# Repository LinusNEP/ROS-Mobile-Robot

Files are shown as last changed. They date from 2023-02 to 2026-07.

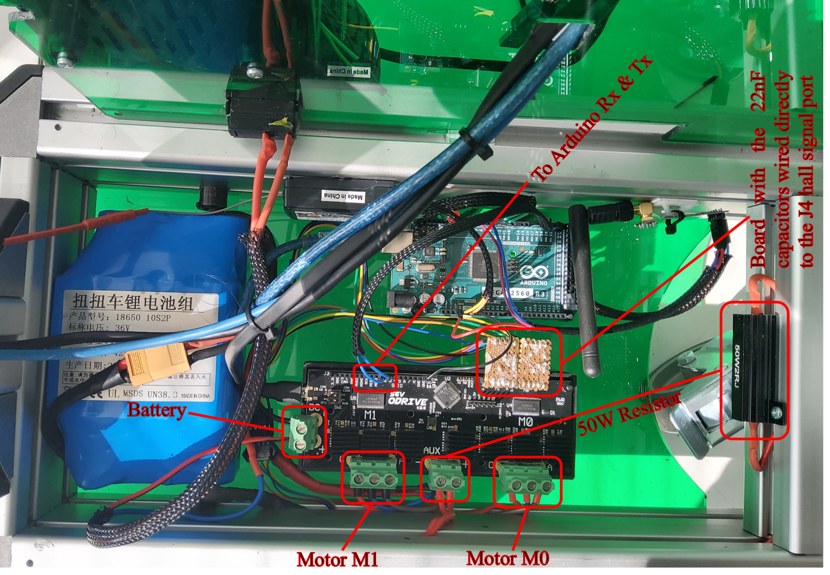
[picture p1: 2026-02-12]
docs/gallery-4.png

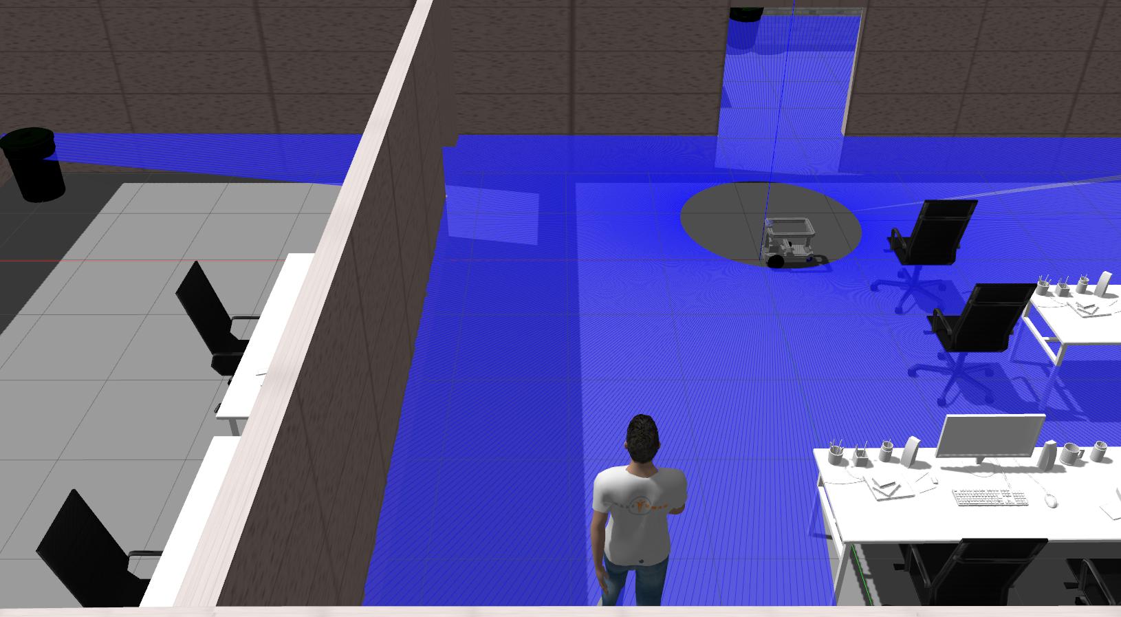
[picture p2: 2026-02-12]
docs/gallery-2.jpg

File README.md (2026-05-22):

## ROMR: A ROS-Based Open-Source Mobile Robot






ROMR is an open-source, low-cost, high-payload autonomous platform designed for research, logistics, and education. This repository contains the necessary files for its  design and development. ROMR utilises off-the-shelf (OTS) components, additive-manufactured parts, aluminium profiles, and a consumer hoverboard with high-torque brushless direct current (BLDC) motors. It is fully compatible with the robot operating system (ROS), has a maximum payload of 90kg, and costs less than $1500. Furthermore, ROMR offers a simple yet robust framework for contextualising simultaneous localisation and mapping (SLAM) algorithms, an essential prerequisite for autonomous robot navigation.

All the design, construction and software files are publicly available under the GNU GPL v3 license. A descriptive video of ROMR can be found at https://osf.io/ku8ag.

More information can be found on the [Project Website](https://linusnep.github.io/ROS-Mobile-Robot/).

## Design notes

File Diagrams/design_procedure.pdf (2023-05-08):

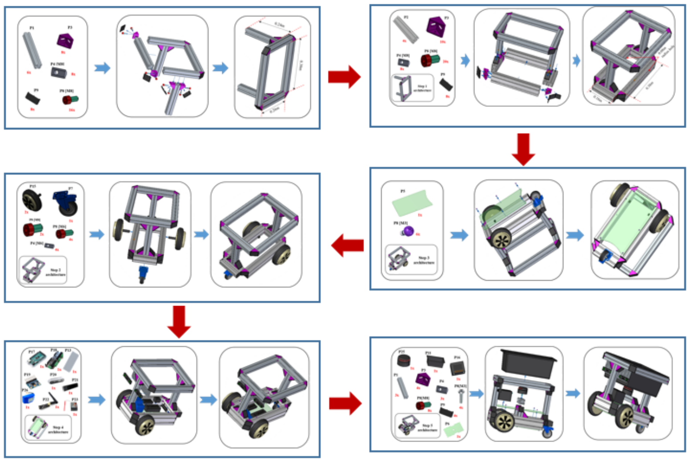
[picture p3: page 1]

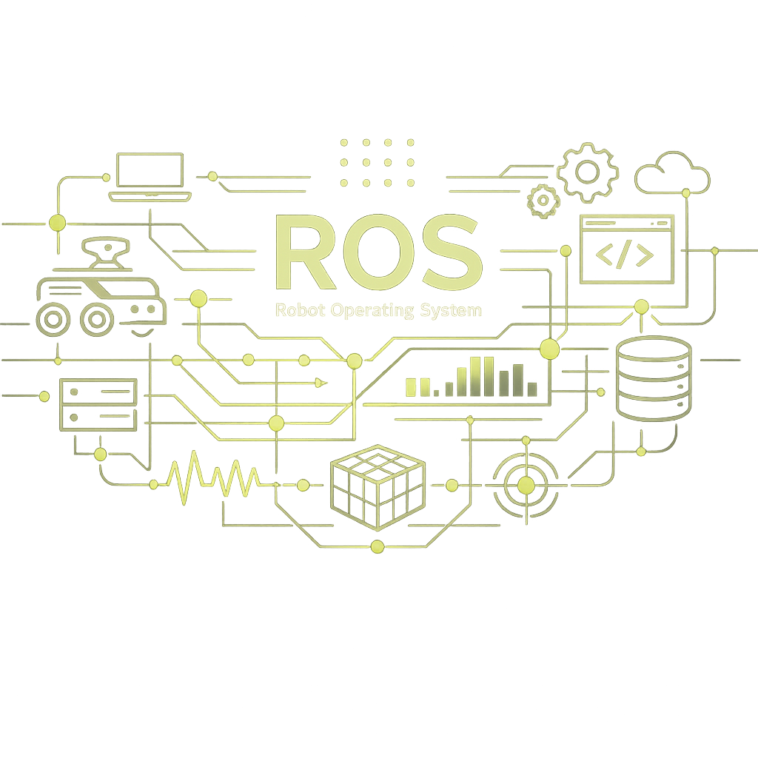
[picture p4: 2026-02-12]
docs/feature-ros.png

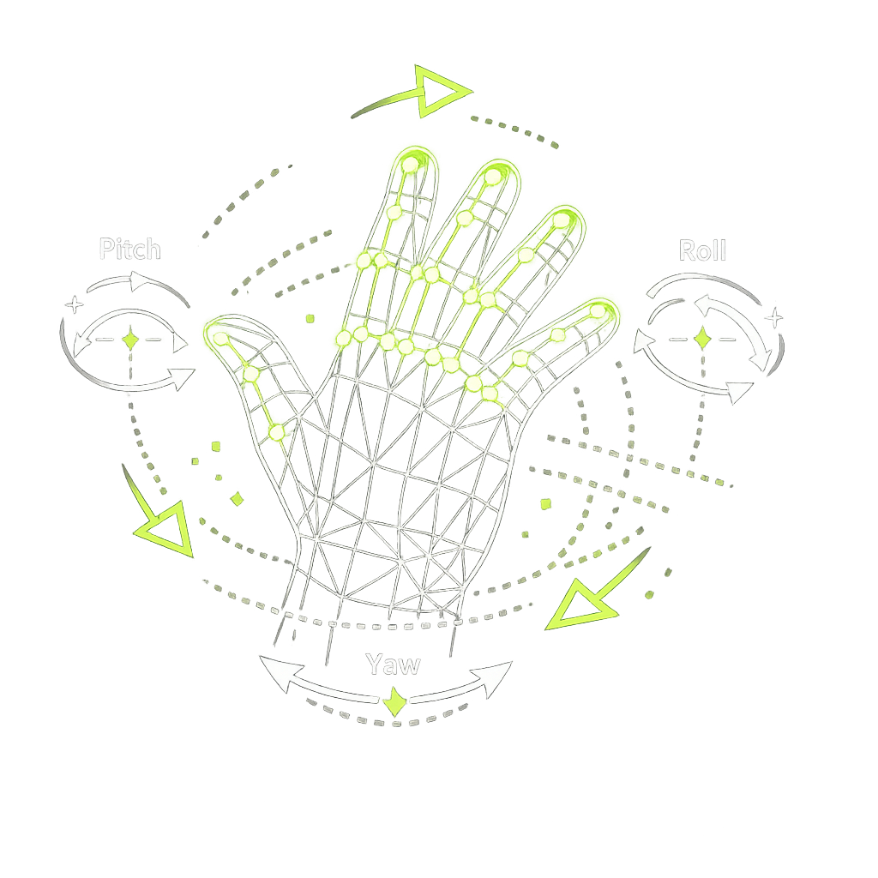
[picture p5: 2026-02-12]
docs/feature-gesture.png

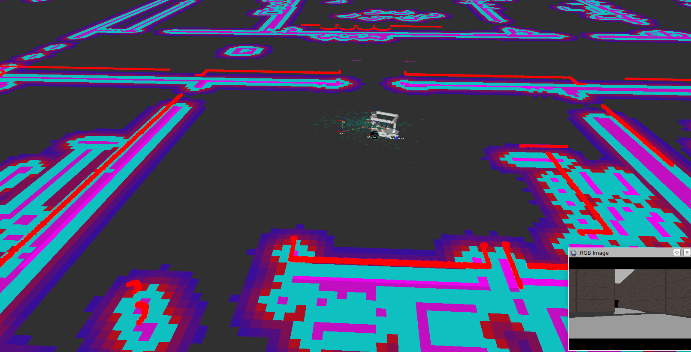
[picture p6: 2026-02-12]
docs/gallery-3.png

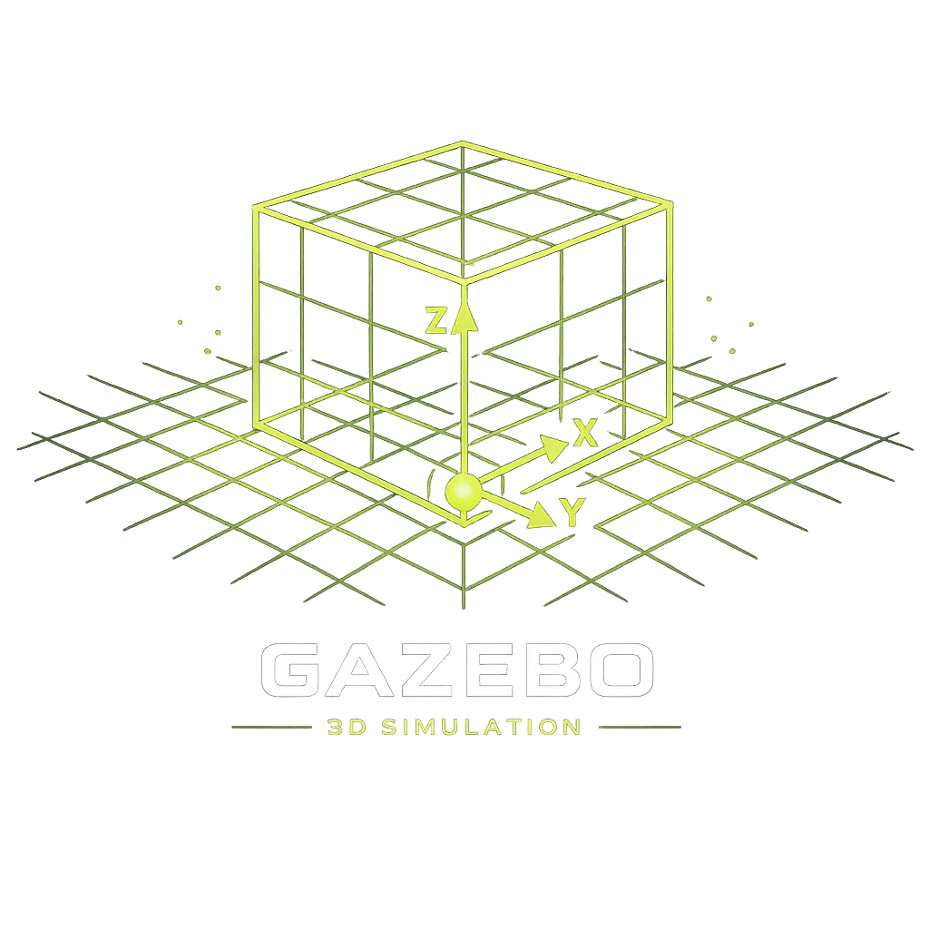
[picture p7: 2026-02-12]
docs/feature-simulation.png

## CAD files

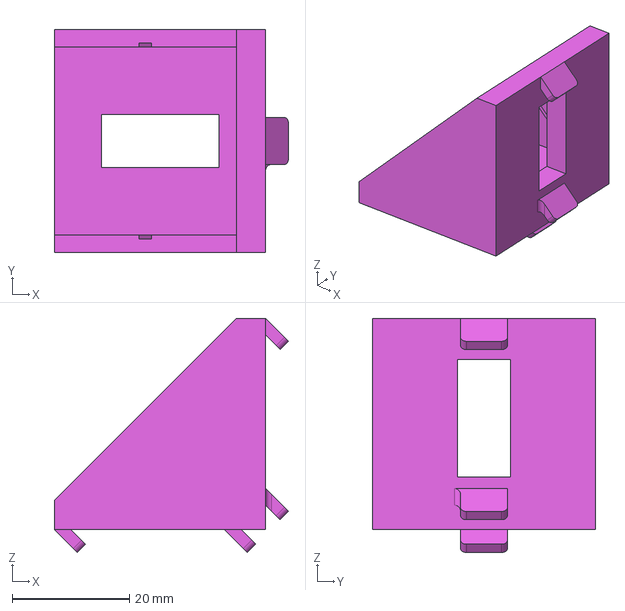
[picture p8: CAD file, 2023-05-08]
CAD & PNG Files/Corner_bracket_I_type.stp
39.9 x 38.0 x 39.9 mm

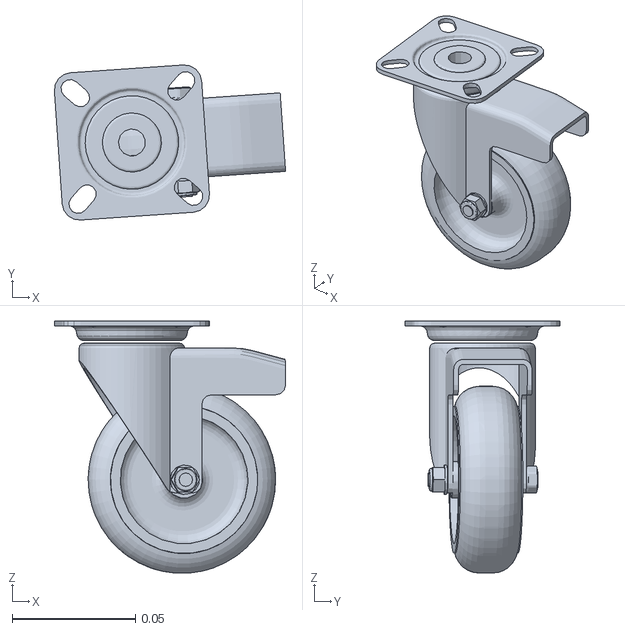
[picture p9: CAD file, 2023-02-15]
romr_ros/src/meshes/casterwheel.STL
0.094 x 0.063 x 0.102

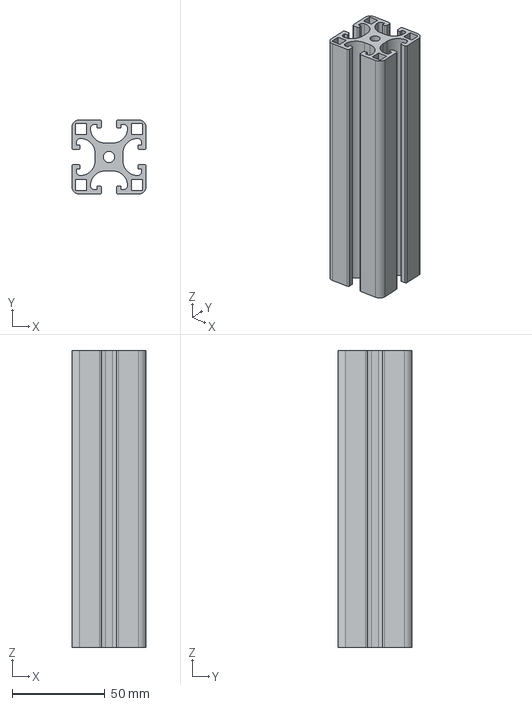
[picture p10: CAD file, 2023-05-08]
CAD & PNG Files/Alu_profil_40x40x165.stp
40.0 x 40.0 x 160.0 mm

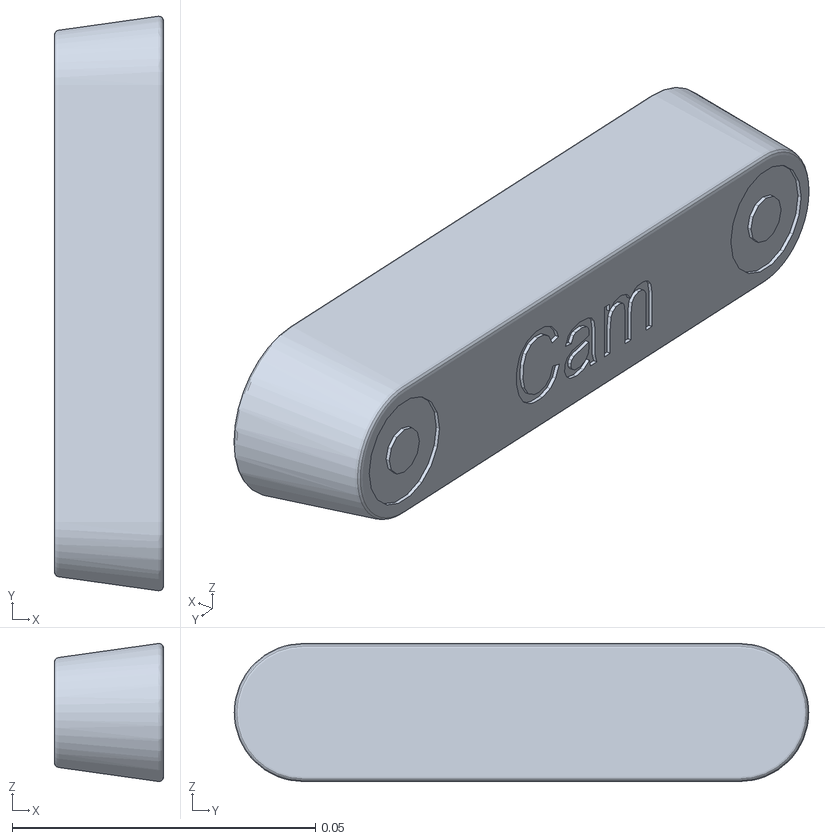
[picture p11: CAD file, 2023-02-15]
romr_ros/src/meshes/camerad435i.STL
0.018 x 0.0948 x 0.0228

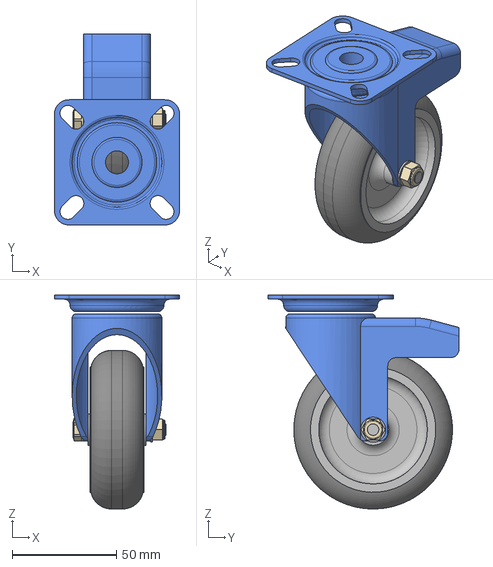
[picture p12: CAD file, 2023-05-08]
CAD & PNG Files/Swivel caster.stp
60.0 x 91.5 x 102.5 mm

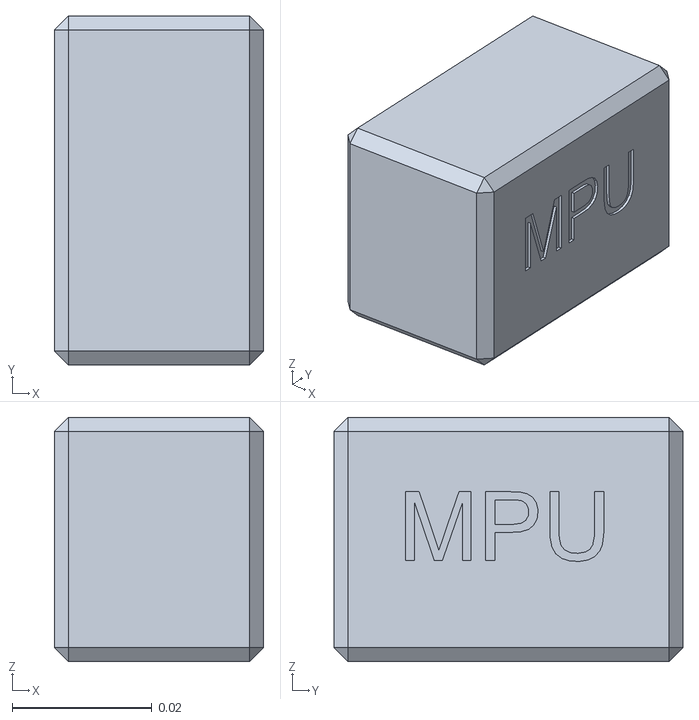
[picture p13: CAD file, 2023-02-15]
romr_ros/src/meshes/imu.STL
0.03 x 0.05 x 0.035

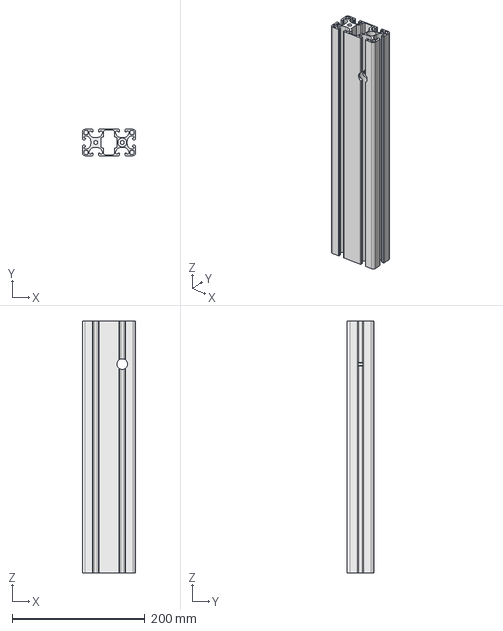
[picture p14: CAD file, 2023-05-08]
CAD & PNG Files/Alu_profil_80x40.stp
80.0 x 40.0 x 380.0 mm

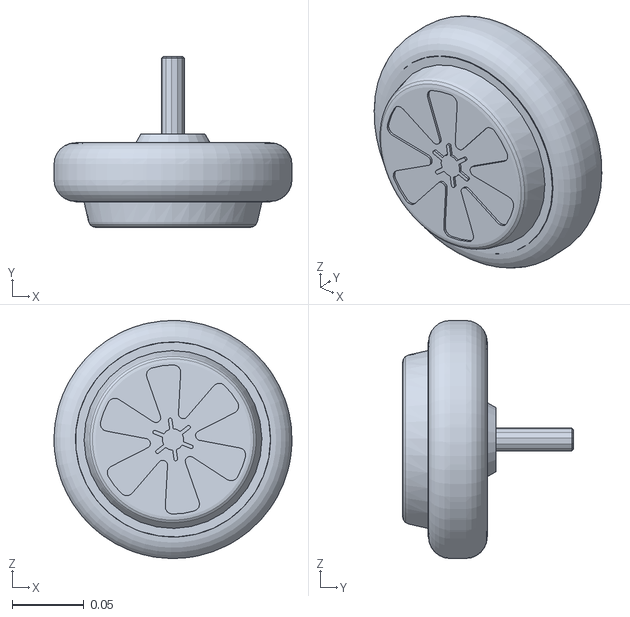
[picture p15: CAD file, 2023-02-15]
romr_ros/src/meshes/rightwheel.STL
0.166 x 0.119 x 0.166

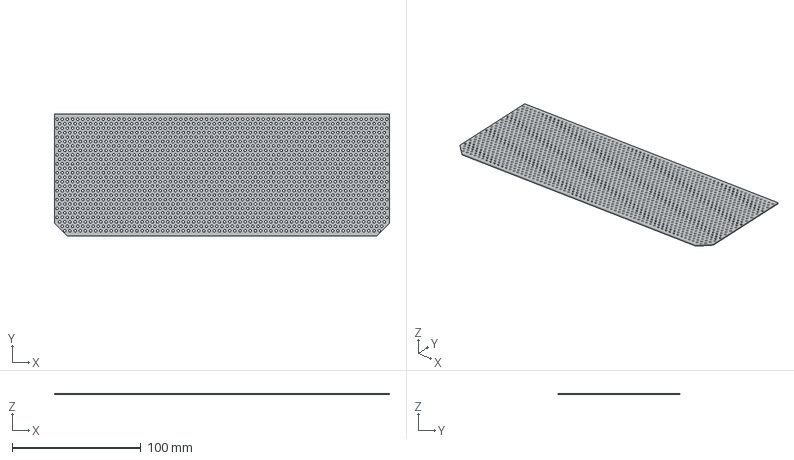
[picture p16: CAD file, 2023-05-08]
CAD & PNG Files/Holeplate_front.stp
260.0 x 95.0 x 1.00 mm

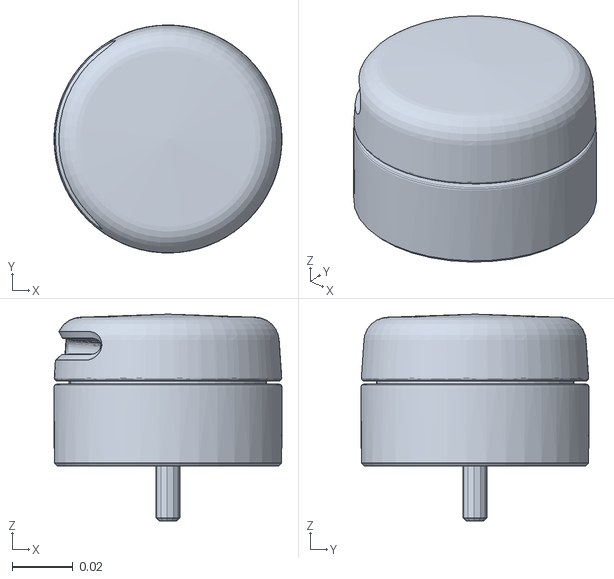
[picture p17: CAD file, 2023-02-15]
romr_ros/src/meshes/lidar.STL
0.075 x 0.075 x 0.068

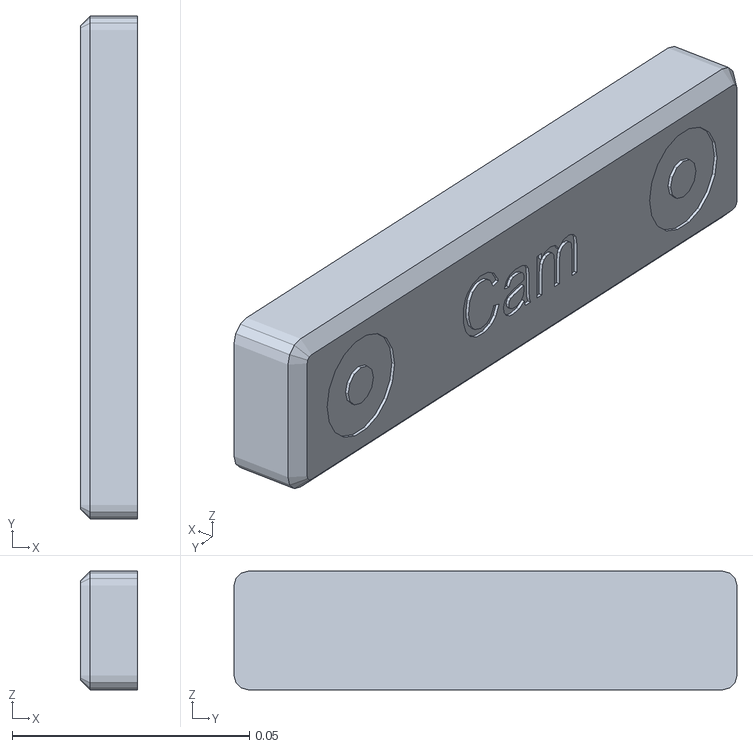
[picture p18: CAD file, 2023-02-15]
romr_ros/src/meshes/camerat265.STL
0.012 x 0.106 x 0.025

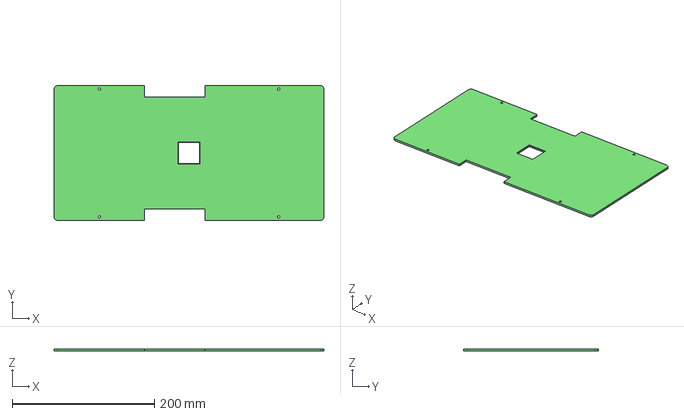
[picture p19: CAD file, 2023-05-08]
CAD & PNG Files/Top_Cover.stp
380.0 x 190.0 x 3.00 mm

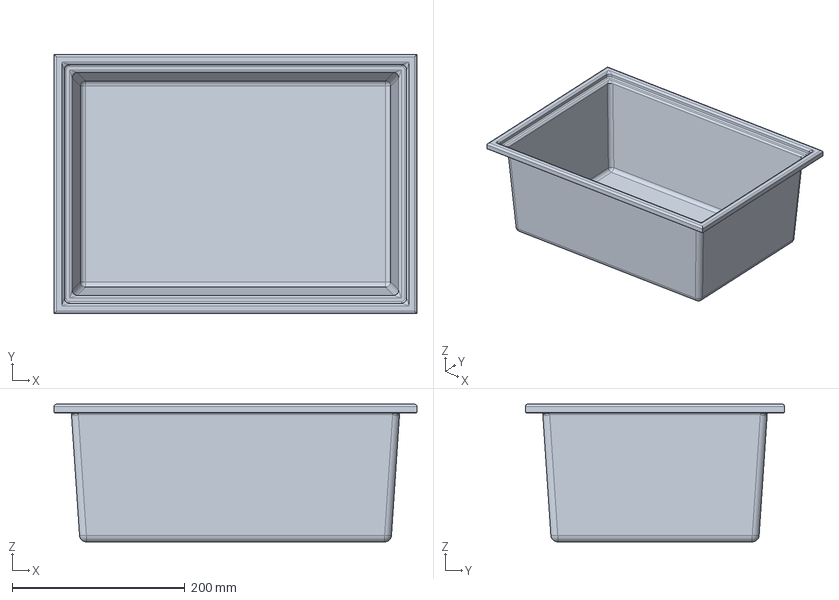
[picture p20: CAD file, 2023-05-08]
CAD & PNG Files/0.42x0.32x0.15m box.stp
420.0 x 300.0 x 159.4 mm

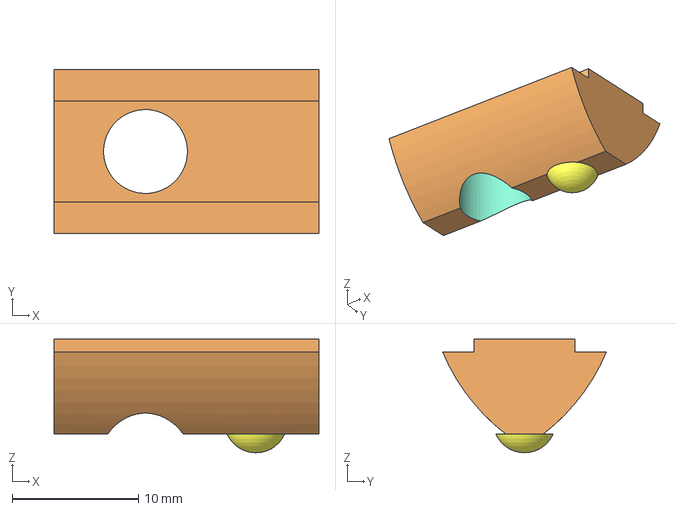
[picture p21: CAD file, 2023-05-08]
CAD & PNG Files/Mountig_Bracket_M8.stp
21.0 x 13.0 x 9.00 mm

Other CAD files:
romr_ros/src/meshes/leftwheel.STL
CAD & PNG Files/Corner_bracket_cover_cap.stp
CAD & PNG Files/Drive_Wheel.stp
CAD & PNG Files/Bottom_Cover.stp
CAD & PNG Files/Assembly_Robot.x_t
CAD & PNG Files/Bolt_M8x16.stp
CAD & PNG Files/lock_nut.stp
CAD & PNG Files/rplidar_base_holder.STL

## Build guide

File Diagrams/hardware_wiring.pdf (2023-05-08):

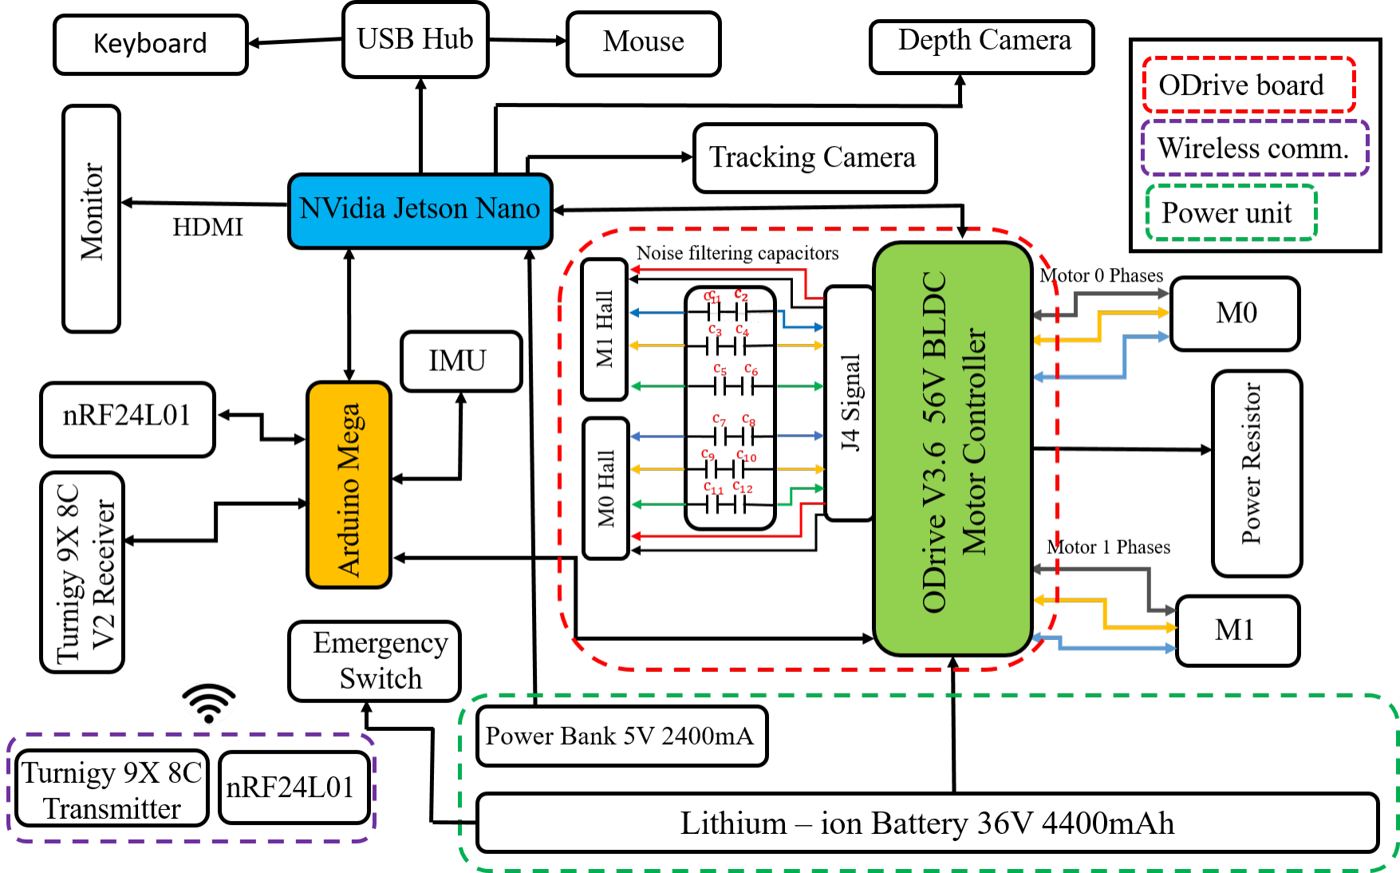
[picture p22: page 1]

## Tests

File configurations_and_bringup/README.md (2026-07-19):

# ROMR ODrive Calibration & Bringup

This directory provides everything needed to get started with ROMR setup and calibration. The structure is as follows: configure parameters, calibrate motors and halls, verify operation over USB, wire up the Arduino, then stack ROS on top. Each step is independent and builds on the last.

---

## Hardware

- **ODrive 3.6** (24 V or 56 V variant) with firmware 0.5.4
- **Two hoverboard hub motors** with 15 pole pairs and 3 hall sensors each
- **Arduino Mega 2560**
- **Jetson Nano** running Ubuntu 18.04 + ROS 1 Melodic (or compatible, e.g., Laptop or Mini-PCs: ROS Noetic and ROS 2)
- **36 V Li-ion battery pack** (10S), optionally with brake resistor
- **RC transmitter/receiver** with at least 3 channels (for RC control)
- **Android device** with the ROS-Mobile app (for WiFi teleop)

If your setup differs, e.g., different ODrive board, different motors, different battery, then the constants at the top of `odrive_parameter_configuration.py` **must be reviewed** before running. Voltage trip levels in particular are safety-critical: wrong values either prevent motor start or cause a fault on the first hard brake.

---

## File overview

### Python - ODrive host scripts

| File | Purpose |
|---|---|
| `odrive_parameter_configuration.py` | Erases all ODrive config and applies ROMR parameters. Run **once** initially, or after firmware changes. |
| `odrive_calibration.py` | Calibrates both motors (R/L) and hall encoders. Run after parameter configuration. |
| `odrive_diagnose.py` | Reads all relevant ODrive state. Non-destructive. Use for troubleshooting. |
| `test_halls.py` | Validates hall sensor wiring by watching `hall_state` while you rotate wheels by hand. |
| `fix_hall_pullups.py` | Non-destructive fix if hall GPIOs are stuck in plain `DIGITAL` mode instead of `DIGITAL_PULL_UP`. |
| `enable_uart.py` | Enables UART A on the ODrive for Arduino communication. Non-destructive. |
| `set_startup_behavior.py` | Explicitly ensures the ODrive boots to IDLE and does not auto-arm. Non-destructive. |

### Arduino - low-level firmware

| File | Purpose |
|---|---|
| `rc_remote_control.ino` | RC teleoperation sketch. Reads 3 PWM channels, commands the ODrive over UART. Includes signal-loss failsafe and stick deadband. |
| `ros_mobile_control.ino` | ROS-compatible sketch. Subscribes to `/cmd_vel` and `/robot/arm`, publishes `/wheel_vel` for host-side odometry. |
| `gesture_handheld.ino` | Handheld transmitter: MPU6050 IMU → nRF24L01+. Maps tilt to velocity commands. Arm button must be held. |
| `gesture_receiver.ino` | Robot-side receiver: nRF24L01+ → ODrive. Standalone, no ROS required. |

### ROS - host-side (Jetson Nano)

| File | Purpose |
|---|---|
| `romr_odom_node.py` | Integrates `/wheel_vel` into `/odom` + TF. |
| `cmd_vel_watchdog.py` | Forwards `/cmd_vel_raw` → `/cmd_vel`, zeroing on input loss. Safety-critical for WiFi teleop. |
| `romr_bringup.launch` | Launches rosserial, odom node, and watchdog together. |
| `romr.service` | Optional systemd unit for auto-start on boot. |

---

## Safety rules - read first

1. **Always put the robot on a stand with wheels off the ground** until all bringup and directionality tests are complete. The robot moving unexpectedly is genuinely dangerous.
2. **Do not skip the failsafe test** (step 8 in RC bringup below). If a signal-loss disarm fails, the robot will not stop when you lose the transmitter, and at some point, you will.
3. **Know where the physical power switch is.** `Ctrl-C` is not a safety mechanism.
4. **Keep a hand near the e-stop / battery disconnect during first runs**, especially for the first time under its own weight.

---

## Bringup sequence

### 1. Install prerequisites

On the host machine (your laptop or the Jetson, wherever you'll run the configuration from):

```bash
pip3 install --user odrive==0.5.4
```

The exact version matters; the ODrive tool API shifted between 0.5. x and 0.6. x.
Scripts here target 0.5.4.

Verify:

```bash
odrivetool --version
```

### 2. Parameter configuration

Connect the ODrive to the host via USB. No motors need to be spinning. This step just writes constants to flash.

```bash
python3 odrive_parameter_configuration.py
```

**This erases any existing ODrive configuration.** You should run this exactly once at the start of the bringup process, or whenever you change firmware or hardware. Do not rerun it casually. It wipes the motor and encoder calibration, and you'll have to redo those.

Expected output ends with:

```
Done. Now run odrive_calibration.py with wheels free to spin.
```

The `ObjectLostError` during save is normal. USB drops when the ODrive reboots.

**Review the constants at the top of the script before running** if your
hardware differs from the ROMR defaults. The ones most likely to need tuning:

| Constant | Default | When to change |
|---|---|---|
| `DC_BUS_OVERVOLTAGE` | 48.0 | Match your ODrive variant (24 V board: 28; 56 V board: 56) |
| `DC_BUS_UNDERVOLTAGE` | 30.0 | Lower for smaller battery, higher for larger |
| `BRAKE_RESISTANCE_OHMS` | 0.5 | Whatever resistor you actually have |
| `ENABLE_BRAKE_RESISTOR` | True | False if none wired |
| `VEL_LIMIT` | 3.0 turns/s | Starts conservative; raise once trusted |
| `CURRENT_LIM` | 20.0 A | Motor-dependent |

### 3. Calibration

With the robot on a stand, both wheels free to spin:

```bash
python3 odrive_calibration.py
```

You'll be prompted to confirm with `YES` (case-sensitive). The script then runs, sequentially on each axis:

1. **Motor calibration**, you will hear a short beep. Measures phase resistance and inductance.
2. **Hall polarity calibration**, there will be a brief wheel motion.
3. **Encoder offset calibration**, there will be a longer wheel motion, ~150 rad scan.

Total time: 60–90 seconds.

Expected healthy values for hoverboard motors: phase resistance 0.15–0.25 Ω, inductance 300–500 µH. Both axes should end with `encoder OK` and the run should save successfully.

#### If calibration fails

| Symptom | Cause | Fix |
|---|---|---|
| `phase inductance 0.0` | Motor cal didn't run. Bad phase wire, undervoltage, or motor not connected | Check phase wires; verify `vbus_voltage` with `odrive_diagnose.py` |
| `encoder error 0x200` (illegal hall state) | Hall wiring, stuck hall, or EMI during motion | Run `test_halls.py`; check 5 V to halls; try re-running |
| `motor error 0x40` (phase resistance out of range) | One phase wire with high contact resistance | Reseat phase connectors |
| Script exits before axis 1 | Axis 0 failed; script aborts on first error | Fix axis 0 first, rerun |
| Halls frozen at single value in `test_halls.py` | GPIO modes wrong (plain `DIGITAL` instead of `DIGITAL_PULL_UP`) | Run `fix_hall_pullups.py` |

A flaky first-attempt failure that succeeds on retry with no changes usually
indicates marginal EMI on hall lines. It'll work, but consider physically
routing hall cables away from phase wires if it keeps recurring.

### 4. Verify calibration via Python (mandatory before Arduino)

Do not skip this. With the robot still on a stand:

```python
import odrive, time
from odrive.enums import AXIS_STATE_CLOSED_LOOP_CONTROL, AXIS_STATE_IDLE

odrv0 = odrive.find_any()

odrv0.axis0.requested_state = AXIS_STATE_CLOSED_LOOP_CONTROL
odrv0.axis1.requested_state = AXIS_STATE_CLOSED_LOOP_CONTROL
time.sleep(0.5)

odrv0.axis0.controller.input_vel = 0.5
odrv0.axis1.controller.input_vel = 0.5
time.sleep(3)

odrv0.axis0.controller.input_vel = 0
odrv0.axis1.controller.input_vel = 0
time.sleep(0.5)
odrv0.axis0.requested_state = AXIS_STATE_IDLE
odrv0.axis1.requested_state = AXIS_STATE_IDLE
```

Both wheels should spin smoothly for 3 seconds. Watch for:
- Smooth rotation (no grinding, no shaking)
- No errors, check with `dump_errors(odrv0)` in `odrivetool`
- Consistent speed between the two wheels

Which direction they spin doesn't matter yet. The Arduino sketches correct that via `M0_DIRECTION` / `M1_DIRECTION`.

### 5. Enable UART for Arduino

```bash
python3 enable_uart.py
```

Non-destructive; just turns on UART A and sets the baudrate to 115200.

### 6. Wire the Arduino Mega to the ODrive

Power off both devices first.

| Mega | ODrive v3.6 |
|---|---|
| Pin 16 (TX2) | GPIO 1 |
| Pin 17 (RX2) | GPIO 2 |
| GND | GND |

**The ground wire is not optional.** Missing common ground is the #1 cause of "everything looks right but no communication." The ODrive and Mega are separately powered; the ground wire gives their UART signals a shared reference.

The Mega gets its power from USB (during development) or a 7–12 V barrel jack (in the field). The ODrive gets its power from the main battery. Do not try to power one from the other.

### 7. RC bringup

See the `rc_remote_control.ino` header comments for RC receiver wiring:
- CH1 (steering) → pin 2
- CH2 (throttle) → pin 3
- CH3 (arm/disarm) → pin 18

Full bringup steps:

1. Transmitter **off**, arm switch in disarmed position.
2. Power up the ODrive, then plug the USB into the Mega.
3. Open Arduino Serial Monitor at 115200 baud. Should see:
   `ROMR RC control ready. Flip the arm switch to enable motors.`
4. Turn on the transmitter. Watch `th`, `st`, `md` values respond to stick
   movement. `md` ≈ 1000 when arm switch is down, ≈ 2000 when up.
5. Flip arm switch. Should see `ARM: closed-loop control` in the log.
6. Gently push the throttle. Check wheel direction:
   - Both forward → good
   - Both backward → flip both `M*_DIRECTION` signs
   - One each way → flip the one going wrong
7. Test steering: with the throttle centred, move the steering stick. Wheels should counter-rotate.
8. **Failsafe test:** With the arm on and the throttle pushed, turn the transmitter off. Within 300 ms, wheels must stop, and the log shows `DISARM: idle`.

Only after step 8 passes should you put wheels on the ground.

### 8. ROS bringup on Jetson Nano

First, set up ROS networking. In `~/.bashrc` on the Nano:

```bash
export ROS_MASTER_URI=http://<nano-ip>:11311
export ROS_IP=<nano-ip>
```

Replace `<nano-ip>` with the actual LAN IP (e.g. `192.168.1.42`). The numeric IP is important — hostname resolution from Android is unreliable.

Flash `ros_mobile_control.ino` to the Mega (replaces the RC sketch). Then on the Nano:

```bash
roslaunch romr_bringup romr_bringup.launch
```

**Motors stay IDLE after launch.** You must arm explicitly.

In the ROS-Mobile app on your phone (same WiFi):

1. Master tab → set Master URI to `http://<nano-ip>:11311`, Master IP to `<nano-ip>` → Connect.
2. Dashboard → add a **Joystick** widget: topic `/cmd_vel_raw`, type `geometry_msgs/Twist`, axes mapped to `linear.x` (fwd/back) and `angular.z` (turn).
3. Dashboard → add a **Button** widget as a dead-man switch: topic `/robot/arm`, type `std_msgs/Bool`, on-press value `true`, on-release value `false`. The motor arms while the button is held and disarms when you release. This is the safest arming pattern for teleop.
4. Optionally add a **Logger** widget on `/robot/armed` and `/odom` to see feedback.

You can also arm/disarm from the Nano shell:
```bash
rostopic pub -1 /robot/arm std_msgs/Bool "data: true"
rostopic pub -1 /robot/arm std_msgs/Bool "data: false"
```

**Three layers of safety protect you:**

1. **Explicit arming**: motors won't spin until you publish `true` on `/robot/arm`. No boot-time or launch-time auto-arm anywhere.
2. **Arduino-side cmd_vel watchdog**: if `/cmd_vel` stops arriving for 500 ms while armed, the Arduino disarms the ODrive itself. Protects against rosserial hangs.
3. **Host-side cmd_vel_watchdog**: forwards `/cmd_vel_raw` → `/cmd_vel` and publishes zeros when the raw input goes silent. Protects against the app crashing or the phone losing WiFi.

You can verify arming works by watching `/robot/armed`. It should go true within ~100 ms of publishing `true` on `/robot/arm`.

### 9. Optional: gesture control (third teleop mode)

An alternative teleop option that works independently of ROS and WiFi. Uses a handheld Arduino with an MPU6050 IMU and nRF24L01+ radio to send tilt-derived velocity commands directly to the robot's Arduino.

**Hardware on the handheld side:**
- Arduino Uno / Nano / Pro Mini
- MPU6050 IMU on I2C (SDA=A4, SCL=A5)
- nRF24L01+ on SPI (MOSI=11, MISO=12, SCK=13, CE=7, CSN=8)
- Momentary push button between pin 2 and GND (arm button)
- 3.3 V power for the nRF24 - do NOT power it from the Arduino's 5 V rail, use a regulator or a dedicated 3.3 V supply
- Small LiPo or AA pack

**Hardware on the robot side:**
- A second nRF24L01+ plugged into the Mega's SPI bus (MOSI=51, MISO=50, SCK=52, CE=9, CSN=10)
- Flash `gesture_receiver.ino` to the Mega (replaces RC or ROS sketch)

**Bringup:**

1. Flash `gesture_handheld.ino` to the handheld Arduino. On boot, it calibrates the gyro (hold still for ~2 seconds, LED solid during cal).
2. Flash `gesture_receiver.ino` to the robot Mega.
3. Open Arduino Serial Monitor at 115200 on the robot side. You should see `lin=0.00 ang=0.00 arm=0 armed=0 age=...ms pkt#=N`. If `pkt#` increments and `age` stays below ~100 ms, the link is working.
4. Robot still on a stand. Hold the handheld level, press and HOLD the arm button. You should see `arm=1` and `armed=1` on the robot serial.
5. Gently tilt the handheld nose-down. The robot should drive forward. Tilt right → robot turns right. Release the arm button → motors disarm immediately.
6. **Failsafe test:** with motors armed, power off the handheld while holding the button. Within 300 ms, the robot should disarm.

**Adjusting feel:**
- `MAX_LIN_VEL`, `MAX_ANG_VEL`: top speeds at full tilt
- `TILT_DEADBAND_DEG`: how much slack around the level before motion starts
- `TILT_MAX_DEG`: tilt angle where you hit top speed
- `INVERT_PITCH`, `INVERT_ROLL`: flip either axis if mounting is different

**Note:** the handheld and robot must use matching `RADIO_ADDRESS` and
`RADIO_CHANNEL`. If you build multiple ROMRs, give each pair a unique
address.

### 10. Optional: headless auto-start

Once the manual launch is stable, install the systemd service:

```bash
sudo cp romr.service /etc/systemd/system/
sudo systemctl daemon-reload
sudo systemctl enable romr.service
sudo systemctl start romr.service
```

Check status with `systemctl status romr` and live logs with `journalctl -u romr -f`. Review the `User=`, paths, and environment in `romr.service` before enabling.

---

## Troubleshooting

**Arduino is flashing, but the motors don't respond.** Verify UART wiring (TX on one end → RX on the other, not TX→TX) and common ground. Test communication independently: from `odrivetool`, confirm `odrv0.axis0.error == 0` and
`dump_errors(odrv0)` shows nothing. Then try a basic UART loopback test before involving the ODrive.

**ROS-Mobile app connects, but `/cmd_vel_raw` is empty.** The Android app's rosjava stack needs the numeric `ROS_IP` set on the Nano; hostname won't work. `rostopic list` should show the topic even before the app moves the
stick; if not, check firewall on the Nano (`sudo ufw status`; disable or open port 11311 and TCPROS range).

**Robot moves, but odom drifts badly.** Some drift is expected from wheel-based odometry (no IMU fusion). Excessive drift usually means `wheel_base` is wrong in `romr_odom_node.py`, or the motor velocity scaling in the sketch is
off. Verify by commanding 1 m/s forward, driving in a straight line, and checking that `/odom` reports ~1 m/s.

**Calibration keeps failing with an illegal hall state despite pullups being correct.** It's likely physical EMI. Solutions in order of effort: enable `ignore_illegal_hall_state = True` (via `retry_axis1.py`); route hall cables
away from motor phase wires; shorten hall cables; add a ferrite bead; use shielded cable for halls.

**The ODrive loses USB connection during save.** Normal. Every `save_configuration()` call triggers a reboot to commit flash, and USB drops for ~2 seconds. The script's `ObjectLostError` / "disappeared" message is expected.

---

## Recovering from a bad state

If something goes wrong and you're unsure what's in the ODrive's flash:

```bash
python3 odrive_diagnose.py
```

Gives you a full dump of config and error state. From there:

- Any `motor.error` or `encoder.error` → run `odrive_calibration.py` again
- Any `axis.error` that won't clear → power cycle and try again
- Wrong pole_pairs, cpr, or control_mode → rerun `odrive_parameter_configuration.py` (wipes calibration, but recovers known-good config)
- Truly stuck → `odrv0.erase_configuration()` in odrivetool, then restart the bringup sequence from step 2

---

## Acknowledgement

The calibration script structure is inspired by the ODrive hoverboard tutorial (docs.odriverobotics.com) and Austin Owens' robodog config. The ROS-Mobile app is developed by Nils Rottmann.

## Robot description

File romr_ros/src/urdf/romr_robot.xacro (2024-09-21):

<?xml version="1.0" encoding="utf-8"?>

<robot name="romr_ros" xmlns:xacro="http://www.ros.org/wiki/xacro">
<xacro:include filename="$(find romr_ros)/urdf/romr_materials.xacro" />
<xacro:include filename="$(find romr_ros)/gazebo/romr_gazebo_materials.gazebo" />  
<xacro:include filename="$(find romr_ros)/gazebo/romr_gazebo_physics.gazebo" />
<xacro:include filename="$(find romr_ros)/gazebo/romr_gazebo_plugins.gazebo" />
 
  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
  
  <xacro:macro name="footprint_inertia" params="m w h d">
    <inertial>
      <origin xyz="0 0 0" rpy="0 0 0"/>
      <mass value="${m}"/>
      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
    </inertial>
  </xacro:macro>
  
  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   
  <link name="base_footprint">
    <xacro:footprint_inertia m="0" w="0" d="0" h="0"/>
  </link>
  
  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
  <joint name="base_joint" type="fixed">
    <parent link="base_link"/>
    <child link="base_footprint"/>
    <origin xyz="0.0 0.0 -0.14" rpy="0 0 0"/> 
  </joint>
  
  <link name="base_link">
    <inertial>
      <origin xyz="-0.0374777931065171 -0.000742607274570373 0.0517646177576365" rpy="0 0 0" />
      <mass value="5.79174328389446" />
      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
    </inertial>
    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
  </link>
  
  <link name="rightwheel_link">
    <inertial>
      <origin xyz="-1.2143E-17 0.033904 1.3878E-17" rpy="0 0 0" />
      <mass value="1.0582" />
      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
    </inertial>
    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
  </link>
  <joint name="rightwheel_joint" type="continuous">
    <origin xyz="-0.12418 0.185 -0.063" rpy="0 0 3.1416" />
    <parent link="base_link" />
    <child link="rightwheel_link" />
    <axis xyz="0 1 0" />
  </joint>
  
  <link name="leftwheel_link">
    <inertial>
      <origin xyz="-2.4286E-17 -0.033904 4.1633E-17" rpy="0 0 0" />
      <mass value="1.0582" />
      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
    </inertial>
    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
  </link>
  <joint name="leftwheel_joint" type="continuous">
    <origin xyz="-0.12418 -0.185 -0.063" rpy="0 0 -3.1416" />
    <parent link="base_link" />
    <child link="leftwheel_link" />
    <axis xyz="0 1 0" />
  </joint>
  
  <link name="casterwheel_link">
    <inertial>
      <origin xyz="-0.0032546 0.0053327 0.013127" rpy="0 0 0" />
      <mass value="0.10255" />
      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
    </inertial>
    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
  </link>
  <joint name="casterwheel_joint" type="fixed">
    <origin xyz="0.25029 -0.01098 -0.1075" rpy="0 0 0" />
    <parent link="base_link" />
    <child link="casterwheel_link" />
    <axis xyz="0 0 0" />
  </joint>
  
  <link name="lidar_link">
    <inertial>
      <origin xyz="0.00050486 -3.7855E-05 -0.025753" rpy="0 0 0" />
      <mass value="0.2064" />
      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
    </inertial>
    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
  </link>
  <joint name="lidar_joint" type="fixed">
    <origin xyz="0.00082049 0.00875 0.12332" rpy="0 0 0" />
    <parent link="base_link" />
    <child link="lidar_link" />
    <axis xyz="0 0 1" />
  </joint>
  
  <link name="imu_link">
    <inertial>
      <origin xyz="-0.015015 -0.00012812 0.00021369" rpy="0 0 0" />
      <mass value="0.05157" />
      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
    </inertial>
    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
  </link>
  <joint name="imu_joint" type="fixed">
    <origin xyz="0.05082 -0.0047896 0.053918" rpy="0 0 0" />
    <parent link="base_link" />
    <child link="imu_link" />
    <axis xyz="0 0 0" />
  </joint>
  
  <link name="camerad435i_link">
    <inertial>
      <origin xyz="0.0094812 3.7095E-05 -7.9734E-05" rpy="0 0 0" />
      <mass value="0.032264" />
      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
    </inertial>
    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
  </link>
  <joint name="camerad435i_joint" type="fixed">
    <origin xyz="-0.20718 -0.08268 0.17016" rpy="0 0 0" />
    <parent link="base_link" />
    <child link="camerad435i_link" />
    <axis xyz="0 0 0" />
  </joint>
  
  <link name="camerat265_link">
    <inertial>
      <origin xyz="0.0061266 3.8568E-05 -1.9004E-05" rpy="0 0 0" />
      <mass value="0.030988" />
      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
    </inertial>
    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
  </link>
  <joint name="camerat265_joint" type="fixed">
    <origin xyz="-0.20118 0.080908 0.16952" rpy="0 0 0" />
    <parent link="base_link" />
    <child link="camerat265_link" />
    <axis xyz="0 0 0" />
  </joint>

</robot>

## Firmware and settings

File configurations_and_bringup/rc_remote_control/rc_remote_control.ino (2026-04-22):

/*
  ROMR RC teleoperation.

  Receives PWM from an RC receiver on three channels:
    CH1 (pin 2)  - steering  (1000-2000 us, 1500 = center)
    CH2 (pin 3)  - throttle  (1000-2000 us, 1500 = center)
    CH3 (pin 18) - arm/disarm (>1500 us = arm motors)

  Commands the ODrive over Serial2 at 115200 baud. ODrive must be
  pre-configured for velocity control (see odrive_parameter_configuration.py).

  Safety features:
    - Signal-loss watchdog on all three channels. If any channel stops
      updating for FAILSAFE_TIMEOUT_MS, motors are forced to IDLE and zero
      velocity is commanded.
    - ISR-shared variables are marked volatile and read atomically.
    - Stick deadband around center eliminates creep from PWM drift.
    - Output slew limiting prevents step-change velocity commands.

  Tune CH1/CH2 pins per your wiring; pins 2, 3, 18 are valid external
  interrupt pins on Arduino Mega (INT0, INT1, INT3). On a Uno, pin 18
  does not exist.
*/

#include <ODriveArduino.h>
#include <Metro.h>

// --- Pin assignments ---
#define CH1_PIN      2      // steering
#define CH2_PIN      3      // throttle
#define CH3_PIN     18      // arm/disarm
#define LED_PIN     13

// --- Motor direction (flip if a wheel spins backward) ---
#define M0_DIRECTION (-1)
#define M1_DIRECTION ( 1)

// --- Control tuning ---
// Output = kp * (pwm_us - 1500). PWM range is typically +/- 500 us,
// so max output = 500 * kp in ODrive velocity units (turns/sec).
// kp = 0.004 -> ~2 turns/sec top speed. Start small, raise once trusted.
#define KP_THROTTLE   0.004f
#define KP_STEERING   0.003f

// Stick deadband in microseconds around 1500 center.
#define STICK_DEADBAND_US 20

// Max change in commanded velocity per control tick (turns/sec per tick).
// At 100 Hz control (10 ms tick) and 0.05 slew, full-range accel takes 0.4 s.
#define VEL_SLEW_PER_TICK 0.05f

// --- PWM thresholds ---
#define PWM_CENTER        1500
#define ARM_THRESHOLD     1500    // CH3 > this means armed
#define PWM_MIN_VALID      900    // below this = invalid/signal lost
#define PWM_MAX_VALID     2100    // above this = invalid/signal lost

// --- Timing (ms) ---
#define BLINK_INTERVAL_MS      200
#define DISPLAY_INTERVAL_MS     50
#define CONTROL_INTERVAL_MS     10     // 100 Hz control loop
#define ARM_INTERVAL_MS         50
#define FAILSAFE_TIMEOUT_MS    300     // must see edges on all channels within this

// --- Baud rates ---
#define PC_BAUD        115200
#define ODRIVE_BAUD    115200

// --- ISR-shared variables: MUST be volatile ---
volatile int steering_us = PWM_CENTER;
volatile int throttle_us = PWM_CENTER;
volatile int mode_us     = 0;

volatile unsigned long ch1_last_edge_ms = 0;
volatile unsigned long ch2_last_edge_ms = 0;
volatile unsigned long ch3_last_edge_ms = 0;

// --- State ---
bool motors_armed = false;
float cmd_right = 0.0f;
float cmd_left  = 0.0f;

ODriveArduino odrive(Serial2);

Metro blink_timer   (BLINK_INTERVAL_MS);
Metro display_timer (DISPLAY_INTERVAL_MS);
Metro control_timer (CONTROL_INTERVAL_MS);
Metro arm_timer     (ARM_INTERVAL_MS);

// ------------------ ISRs ------------------
// Each ISR records the most recent rising edge time and computes the pulse
// width on the falling edge. We also stamp a "last edge" time in ms so the
// main loop can detect signal loss.

void isr_ch1() {
  static unsigned long rise_us = 0;
  if (digitalRead(CH1_PIN)) {
    rise_us = micros();
  } else {
    steering_us = (int)(micros() - rise_us);
  }
  ch1_last_edge_ms = millis();
}

void isr_ch2() {
  static unsigned long rise_us = 0;
  if (digitalRead(CH2_PIN)) {
    rise_us = micros();
  } else {
    throttle_us = (int)(micros() - rise_us);
  }
  ch2_last_edge_ms = millis();
}

void isr_ch3() {
  static unsigned long rise_us = 0;
  if (digitalRead(CH3_PIN)) {
    rise_us = micros();
  } else {
    mode_us = (int)(micros() - rise_us);
  }
  ch3_last_edge_ms = millis();
}

// ------------------ Helpers ------------------

// Atomic snapshot of the ISR-shared variables.
static inline void snapshot(int &st, int &th, int &md,
                            unsigned long &t1, unsigned long &t2, unsigned long &t3) {
  noInterrupts();
  st = steering_us;
  th = throttle_us;
  md = mode_us;
  t1 = ch1_last_edge_ms;
  t2 = ch2_last_edge_ms;
  t3 = ch3_last_edge_ms;
  interrupts();
}

static inline bool pwm_valid(int us) {
  return us >= PWM_MIN_VALID && us <= PWM_MAX_VALID;
}

static inline float slew(float current, float target, float max_step) {
  float d = target - current;
  if (d >  max_step) d =  max_step;
  if (d < -max_step) d = -max_step;
  return current + d;
}

// ------------------ Main tasks ------------------

void set_armed(bool arm) {
  if (arm == motors_armed) return;
  if (arm) {
    Serial.println(F("ARM: closed-loop control"));
    odrive.run_state(0, AXIS_STATE_CLOSED_LOOP_CONTROL, false);
    odrive.run_state(1, AXIS_STATE_CLOSED_LOOP_CONTROL, false);
  } else {
    Serial.println(F("DISARM: idle"));
    odrive.SetVelocity(0, 0);
    odrive.SetVelocity(1, 0);
    odrive.run_state(0, AXIS_STATE_IDLE, false);
    odrive.run_state(1, AXIS_STATE_IDLE, false);
    cmd_right = cmd_left = 0.0f;
  }
  motors_armed = arm;
}

void control_task() {
  int st, th, md;
  unsigned long t1, t2, t3;
  snapshot(st, th, md, t1, t2, t3);

  unsigned long now = millis();
  bool ch1_alive = (now - t1) < FAILSAFE_TIMEOUT_MS && pwm_valid(st);
  bool ch2_alive = (now - t2) < FAILSAFE_TIMEOUT_MS && pwm_valid(th);
  bool ch3_alive = (now - t3) < FAILSAFE_TIMEOUT_MS && pwm_valid(md);
  bool rc_ok = ch1_alive && ch2_alive && ch3_alive;

  if (!rc_ok) {
    // Signal loss: force disarm and command zero.
    set_armed(false);
    return;
  }

  // Apply deadband.
  int th_off = th - PWM_CENTER;
  int st_off = st - PWM_CENTER;
  if (abs(th_off) < STICK_DEADBAND_US) th_off = 0;
  if (abs(st_off) < STICK_DEADBAND_US) st_off = 0;

  float throttle_cmd = KP_THROTTLE * (float)th_off;
  float steering_cmd = KP_STEERING * (float)st_off;

  // Differential mix.
  float target_right = throttle_cmd + steering_cmd;
  float target_left  = throttle_cmd - steering_cmd;

  // Slew-limit to prevent jerky steps.
  cmd_right = slew(cmd_right, target_right, VEL_SLEW_PER_TICK);
  cmd_left  = slew(cmd_left,  target_left,  VEL_SLEW_PER_TICK);

  if (motors_armed) {
    odrive.SetVelocity(0, M0_DIRECTION * cmd_right);
    odrive.SetVelocity(1, M1_DIRECTION * cmd_left);
  }
}

void arm_task() {
  // Only honored if all three RC channels are alive; handled in control_task
  // via set_armed(false) on signal loss.
  unsigned long now = millis();
  bool ch3_alive = (now - ch3_last_edge_ms) < FAILSAFE_TIMEOUT_MS;
  if (!ch3_alive) return;

  bool want_armed = (mode_us > ARM_THRESHOLD);
  set_armed(want_armed);
}

void blink_task() {
  // Steady 200ms blink when RC is alive, fast blink when signal lost.
  unsigned long now = millis();
  bool rc_ok = (now - ch1_last_edge_ms < FAILSAFE_TIMEOUT_MS)
            && (now - ch2_last_edge_ms < FAILSAFE_TIMEOUT_MS)
            && (now - ch3_last_edge_ms < FAILSAFE_TIMEOUT_MS);
  static bool led_state = false;
  static unsigned long last_toggle = 0;
  unsigned long interval = rc_ok ? BLINK_INTERVAL_MS : 50;
  if (now - last_toggle >= interval) {
    led_state = !led_state;
    digitalWrite(LED_PIN, led_state);
    last_toggle = now;
  }
}

void display_task() {
  int st, th, md;
  unsigned long t1, t2, t3;
  snapshot(st, th, md, t1, t2, t3);
  Serial.print(F("th=")); Serial.print(th);
  Serial.print(F(" st=")); Serial.print(st);
  Serial.print(F(" md=")); Serial.print(md);
  Serial.print(F(" armed=")); Serial.print(motors_armed);
  Serial.print(F(" cmdR=")); Serial.print(cmd_right, 3);
  Serial.print(F(" cmdL=")); Serial.println(cmd_left, 3);
}

// ------------------ Arduino entry points ------------------

void setup() {
  pinMode(LED_PIN, OUTPUT);
  pinMode(CH1_PIN, INPUT);
  pinMode(CH2_PIN, INPUT);
  pinMode(CH3_PIN, INPUT);

  Serial.begin(PC_BAUD);
  Serial2.begin(ODRIVE_BAUD);

  attachInterrupt(digitalPinToInterrupt(CH1_PIN), isr_ch1, CHANGE);
  attachInterrupt(digitalPinToInterrupt(CH2_PIN), isr_ch2, CHANGE);
  attachInterrupt(digitalPinToInterrupt(CH3_PIN), isr_ch3, CHANGE);

  // Make sure the ODrive starts idle. Don't auto-arm on boot.
  delay(200);
  odrive.run_state(0, AXIS_STATE_IDLE, false);
  odrive.run_state(1, AXIS_STATE_IDLE, false);

  Serial.println(F("ROMR RC control ready. Flip arm switch to enable motors."));
}

void loop() {
  if (blink_timer.check())   blink_task();
  if (display_timer.check()) display_task();
  if (control_timer.check()) control_task();
  if (arm_timer.check())     arm_task();
}

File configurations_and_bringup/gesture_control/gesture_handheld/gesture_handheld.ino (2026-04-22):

/*
  ROMR Gesture Handheld Transmitter.

  Hardware:
    - Arduino (Uno/Nano/Pro Mini)
    - MPU6050 IMU on I2C (SDA=A4, SCL=A5 on Uno/Nano)
    - nRF24L01+ on SPI:
        MOSI = 11, MISO = 12, SCK = 13
        CE   = 7,  CSN  = 8    (configurable below)
    - Arm button between pin 2 and GND (uses internal pullup)
    - Status LED on pin 13 (built-in)

  Behavior:
    - Reads IMU at 50 Hz
    - Complementary filter for pitch/roll
    - Pitch (nose down) = forward command
    - Roll (right)      = right turn command
    - Transmits {lin_vel, ang_vel, armed, seq, checksum} every 20 ms
    - Arm button must be HELD to arm; release disarms immediately

  Libraries needed (Arduino Library Manager):
    - RF24 by TMRh20
    - MPU6050 by Electronic Cats (or any Wire-based MPU6050 lib)
*/

#include <SPI.h>
#include <RF24.h>
#include <Wire.h>

// ---------------- Pin config ----------------
#define PIN_CE    7
#define PIN_CSN   8
#define PIN_ARM   2
#define PIN_LED   13

// ---------------- Radio config ----------------
// Pipe address must match the receiver exactly. 5 bytes, any values.
const uint8_t RADIO_ADDRESS[5] = { 'R', 'O', 'M', 'R', '1' };
#define RADIO_CHANNEL  76       // 2.476 GHz; avoid common WiFi channels

// ---------------- Tilt mapping ----------------
// Max command velocities at full tilt (tune to taste)
#define MAX_LIN_VEL    0.6f    // m/s  (conservative; raise once trusted)
#define MAX_ANG_VEL    1.2f    // rad/s

// Tilt angles
#define TILT_DEADBAND_DEG   5.0f    // below this = zero command
#define TILT_MAX_DEG       25.0f    // at or above this = max command

// Invert axes if mounting is different than documented
#define INVERT_PITCH   false   // set true if "nose down" should mean backward
#define INVERT_ROLL    false   // set true if "right tilt" should mean left turn

// ---------------- Timing ----------------
#define IMU_PERIOD_MS        20    // 50 Hz sampling
#define TX_PERIOD_MS         20    // 50 Hz transmission
#define LED_BLINK_ARMED_MS   500
#define LED_BLINK_IDLE_MS    100

// ---------------- Packet format ----------------
// Keep this EXACTLY in sync with the receiver sketch.
struct __attribute__((packed)) GesturePacket {
  int16_t lin_vel_mm_s;   // linear velocity * 1000  (m/s -> mm/s)
  int16_t ang_vel_mrad_s; // angular velocity * 1000 (rad/s -> mrad/s)
  uint8_t armed;          // 0 or 1
  uint8_t seq;            // rolling sequence number
  uint8_t checksum;       // XOR of all bytes above
};

// ---------------- Globals ----------------
RF24 radio(PIN_CE, PIN_CSN);

// MPU6050 raw registers
#define MPU6050_ADDR   0x68
#define PWR_MGMT_1     0x6B
#define ACCEL_XOUT_H   0x3B

// Calibration offsets (measured in setup)
int16_t gx_offset = 0, gy_offset = 0, gz_offset = 0;

// Filter state
float pitch_deg = 0.0f;
float roll_deg  = 0.0f;

// Timing
unsigned long last_imu_ms = 0;
unsigned long last_tx_ms = 0;
unsigned long last_led_ms = 0;
bool led_state = false;
uint8_t seq = 0;

// ---------------- MPU6050 helpers ----------------
void mpuWrite(uint8_t reg, uint8_t val) {
  Wire.beginTransmission(MPU6050_ADDR);
  Wire.write(reg);
  Wire.write(val);
  Wire.endTransmission();
}

void mpuReadAll(int16_t &ax, int16_t &ay, int16_t &az,
                int16_t &gx, int16_t &gy, int16_t &gz) {
  Wire.beginTransmission(MPU6050_ADDR);
  Wire.write(ACCEL_XOUT_H);
  Wire.endTransmission(false);
  Wire.requestFrom((uint8_t)MPU6050_ADDR, (uint8_t)14, (uint8_t)true);
  ax = (Wire.read() << 8) | Wire.read();
  ay = (Wire.read() << 8) | Wire.read();
  az = (Wire.read() << 8) | Wire.read();
  Wire.read(); Wire.read();  // temperature, ignored
  gx = (Wire.read() << 8) | Wire.read();
  gy = (Wire.read() << 8) | Wire.read();
  gz = (Wire.read() << 8) | Wire.read();
}

void calibrateGyro() {
  // Hold still for 2 seconds, average zero-rate offsets.
  long sx = 0, sy = 0, sz = 0;
  const int N = 100;
  for (int i = 0; i < N; i++) {
    int16_t ax, ay, az, gx, gy, gz;
    mpuReadAll(ax, ay, az, gx, gy, gz);
    sx += gx; sy += gy; sz += gz;
    delay(20);
  }
  gx_offset = sx / N;
  gy_offset = sy / N;
  gz_offset = sz / N;
}

// ---------------- Tilt -> velocity mapping ----------------
float tiltToCommand(float tilt_deg, float max_vel) {
  // Linear map: deadband..max -> 0..max_vel, with sign preservation
  float mag = fabs(tilt_deg);
  if (mag <= TILT_DEADBAND_DEG) return 0.0f;
  if (mag >= TILT_MAX_DEG)      return (tilt_deg > 0 ? max_vel : -max_vel);
  float frac = (mag - TILT_DEADBAND_DEG) / (TILT_MAX_DEG - TILT_DEADBAND_DEG);
  float cmd  = frac * max_vel;
  return (tilt_deg > 0) ? cmd : -cmd;
}

uint8_t computeChecksum(const GesturePacket& p) {
  const uint8_t* b = (const uint8_t*)&p;
  uint8_t sum = 0;
  // Checksum covers everything except the checksum byte itself
  for (size_t i = 0; i < sizeof(GesturePacket) - 1; i++) sum ^= b[i];
  return sum;
}

// ---------------- Setup ----------------
void setup() {
  pinMode(PIN_ARM, INPUT_PULLUP);
  pinMode(PIN_LED, OUTPUT);

  Serial.begin(115200);
  Serial.println(F("ROMR gesture handheld"));

  Wire.begin();
  Wire.setClock(400000);

  // Wake MPU6050 (PWR_MGMT_1 = 0 clears sleep bit)
  mpuWrite(PWR_MGMT_1, 0x00);
  delay(100);

  Serial.println(F("Calibrating gyro... hold still for 2 seconds"));
  digitalWrite(PIN_LED, HIGH);
  calibrateGyro();
  digitalWrite(PIN_LED, LOW);
  Serial.print(F("Gyro offsets: "));
  Serial.print(gx_offset); Serial.print(' ');
  Serial.print(gy_offset); Serial.print(' ');
  Serial.println(gz_offset);

  // Radio
  if (!radio.begin()) {
    Serial.println(F("FATAL: nRF24 hardware not detected"));
    while (1) {
      digitalWrite(PIN_LED, !digitalRead(PIN_LED));
      delay(50);  // rapid blink = hardware failure
    }
  }
  radio.setPALevel(RF24_PA_HIGH);
  radio.setDataRate(RF24_250KBPS);   // longer range than 1Mbps/2Mbps
  radio.setChannel(RADIO_CHANNEL);
  radio.setPayloadSize(sizeof(GesturePacket));
  radio.setAutoAck(true);
  radio.setRetries(3, 5);            // 3*250us delay, 5 retries
  radio.openWritingPipe(RADIO_ADDRESS);
  radio.stopListening();

  Serial.println(F("Ready. Hold arm button + tilt to drive."));
}
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

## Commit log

2026-02-12 Add ELP 4K Monocular Camera to Sensors list
2026-02-12 Update fmt.Println message from 'Hello' to 'Goodbye'
2026-02-26 Update print statement from 'Hello' to 'Goodbye'

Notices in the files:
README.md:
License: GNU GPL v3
